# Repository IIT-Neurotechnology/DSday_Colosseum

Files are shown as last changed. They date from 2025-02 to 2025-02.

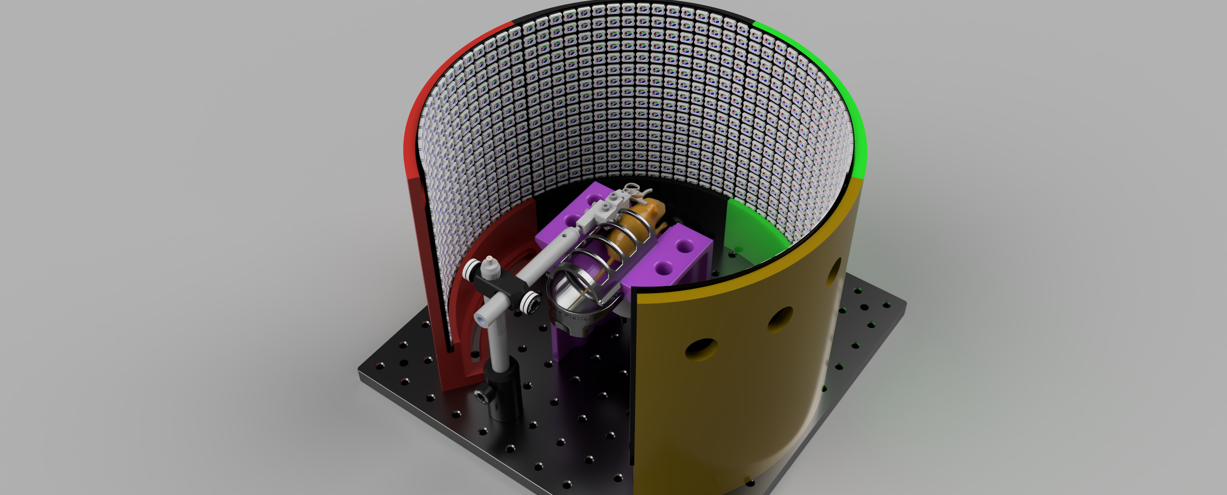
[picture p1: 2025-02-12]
NT_BMP005_004/NT_BMP005_004.png

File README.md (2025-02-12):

# BPOD-based Circular LED COLOSSEUM with Rotary Encoder Control

Render            |  Real
:-------------------------:|:-------------------------:
ed130eb8-e9cf-46bc-b179-3c29f74139bb | 663ee327-6ebf-47c2-a723-3dfb6b113a29

This system integrates a **BPOD** behavioral platform with a **circular LED display** and a **high-resolution rotary encoder**, creating a three-dimensional "colosseum-like" environment for a mouse in a neuroscience experiment. The mouse sits at the center of a 3D-printed, circular arena, surrounded by flexible LED panels. By turning a rotary encoder, the mouse effectively rotates a luminous vertical bar around the "walls" of this arena. Over time, the mouse can learn to anticipate the position of this bar, providing insights into spatial navigation and cognitive mapping.

---

## Hardware Components

- **BPOD Module**  
  Controls experimental states, rewards, and logs events. It synchronizes with the Teensy-based rotary encoder module and the LED display.

- **Rotary Encoder (1024 PPR)**  
  Translates the mouse's rotational input into LED position updates. The ratio `N` defines how many full rotations of the encoder correspond to a complete LED revolution. For example, `N = 2` means two wheel rotations produce one full LED ring rotation.

- **Flexible Circular LED Panels (WS2812B)**  
  - Four 16×16 LED matrices (each containing WS2812B LEDs) arranged in a 2×2 layout, forming a 64×16 (1024 LED) array.  
  - These are curved into a circular shape inside a 3D-printed enclosure.  
  - Each WS2812B LED needs ~1.25 µs per bit, **24 bits** (3 bytes for RGB), plus a ~50 µs reset at the end of the data stream.

- **BPOD Rotary Encoder Module (Teensy-based)**  
  A **Teensy** microcontroller reads the rotary encoder, calculates LED positions, and **sends** data over serial if required. A second Teensy can then handle the actual LED updates, preventing timing conflicts.

---

## Additional Teensy 3.6 for LED Control

To handle the large number of LEDs (1024 WS2812Bs) efficiently, a **second Teensy 3.6** is used **exclusively** for LED updates:

- **Faster LED Updates with FastLED**  
  - The second Teensy runs the **FastLED** library, which manages precise timing for WS2812B signals (~1.25 µs/bit).  
  - This Teensy listens on **Serial5** for packets containing LED bar indices and color commands.  
  - By splitting tasks across two microcontrollers, the rotary encoder readings remain accurate, and LED updates remain flicker-free.

- **Offloading CPU Load**  
  - The first Teensy (rotary encoder module) only sends position data to the second Teensy.  
  - This separation ensures smoother operation, as the CPU-intensive LED data updates occur on a dedicated microcontroller.

- **Two Data Pins for Higher Throughput**  
  - The second Teensy 3.6 drives the LEDs on **pins 18 and 19**, effectively splitting the 1024 LEDs into two parallel strips.  
  - Each LED requires 24 bits of data plus a ~50 µs reset at the end of the data frame. Driving two strips simultaneously nearly halves the total transmission time.

### Approximate Update Frequency Calculation

- **Single-Strip Transmission Time**  
  - Each LED needs 24 bits × 1.25 µs = 30 µs of transmission time per LED.  
  - For 1024 LEDs, total data time = 1024 × 30 µs = 30,720 µs, plus ~50 µs reset ≈ **30.77 ms** per frame.  
  - That’s about **32.5 fps** (frames per second) if you only had a single strip.

- **Two Strips in Parallel**  
  - If you split the 1024 LEDs into two equal strips, each strip updates 512 LEDs in parallel.  
  - Transmission time per strip is roughly 512 × 30 µs = 15,360 µs, plus ~50 µs ≈ **15.41 ms**.  
  - This yields around **65 fps** as a theoretical maximum, assuming continuous updates.

---
397879740-6fc6f9c6-3a99-4fa2-a4de-f5ea3d144b3a

## Software Components

- **BPOD State Machine**  
  Defines trial structures, handles reward timing, and synchronizes LED updates with behavioral events. The LED state can be triggered at certain times or after specific encoder changes, all logged by BPOD.

- **Teensy Firmware (C++ with FastLED)**  
  - **First Teensy** (Encoder Module)  
    Reads the rotary encoder and sends serial messages (via **Serial5**) containing updated LED positions or commands.  
  - **Second Teensy** (Dedicated LED Driver)  
    Receives data on **Serial5**, updates the WS2812B strips on pins 18 and 19, and ensures precise timing.

---

## Functionality

1. **Encoder-to-LED Mapping**  
   The encoder’s angular range maps onto the LED indices forming a circular ring. Each bar corresponds to a specific angular segment. Changing `N` modifies how many full turns of the encoder produce one full 360° LED sweep.

2. **Cylindrical Illusion**  
   The curved LED panels create a wraparound environment, giving the mouse the impression of a cylindrical “colosseum.” Rotating the encoder moves the illuminated bar around the circumference.

3. **Cognitive Task**  
   Mice can learn to anticipate the bar’s position, forming an internal “cognitive map” of the environment. Researchers can adjust difficulty by changing `N`, the **bar width** (`W`), or brightness.

4. **Minimal Updates**  
   Instead of resetting all 1024 LEDs every loop, the firmware switches off only the old bar and lights the new one. This approach minimizes computation, reduces flicker, and helps maintain brightness consistency.

---

## Setup & Calibration

1. **Hardware Assembly**  
   - 3D print the circular enclosure (e.g., on a Prusa) to hold four flexible 16×16 LED panels.  
   - Mount the LED panels around the inner circumference to form a 64×16 (1024 LED) array.  
   - Attach the rotary encoder, ensuring stable mechanical coupling for the mouse’s rotation.  
   - Use one Teensy for the rotary encoder and another Teensy 3.6 (with FastLED) for LED data.  
   - Provide sufficient power and stable wiring (WS2812B can draw significant current).

2. **Firmware & Parameters**  
   - Load the Teensy firmware for the encoder module (handles reading and serial output).  
   - Load the Teensy firmware for the LED driver (handles incoming serial commands and drives LEDs).  
   - Confirm `NUM_LEDS = 1024` (or your actual total), and that two strips of 512 LEDs are mapped to pins 18 & 19.  
   - Set `N` for the desired encoder rotations per 360° sweep. Adjust `W` (the bar width in LEDs) and LED brightness to tune performance and difficulty.

3. **BPOD Integration**  
   - Configure BPOD’s state machine to detect encoder triggers and LED transitions.  
   - Optionally deliver rewards when certain encoder conditions are met.  
   - Use BPOD’s data logging to correlate behavior, encoder events, and LED states.

---

## Maintenance & Troubleshooting

- **LED/Encoder Alignment**  
  If LED positions don’t match the encoder reading, verify the index mapping and `N` factor.  
- **Power Supply**  
  Flickering or dim LEDs may indicate insufficient power or significant voltage drop. Use robust wiring and/or inject power at multiple points.  
- **Frame Rate Optimization**  
  If you need faster updates, switch to 4 pins to achieve a faster parallel communication with the LEDs
- **Serial Communication**  
  Ensure the second Teensy is receiving data correctly on **Serial5** (check baud rate, TX/RX pins).

---

## Conclusion

This integrated system provides a precise, stable, and configurable visual environment for neuroscience experiments. By combining a **BPOD** state machine, a **high-resolution rotary encoder**, and **two Teensy 3.6** boards (one exclusively handling **FastLED** updates), researchers can study spatial cognition in rodents. Efficient partial‐update LED control ensures smooth visuals, aiding in the formation of robust internal cognitive maps in the mouse’s brain.

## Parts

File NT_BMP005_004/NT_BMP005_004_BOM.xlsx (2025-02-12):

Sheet: components request
# | Cod. | Rev. | Q.ty | Mfg. Technology | Material | Notes | Optional column 1 | Optional column 2
1 | NT_BMP005_004 | 1 | 1 | FFF (Fortus400) | any

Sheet: processes
Mgf. Technologies
Additive Mfg. (any)
SLS (ProX6100)
Polyjet (Connex500)
SLA (XFAB3500SD)
FFF (Fortus400)
CNC / Machine Tools
Waterjet
Inserts/Helicoils
Mech. Assembly
Reworked Comp.
Other

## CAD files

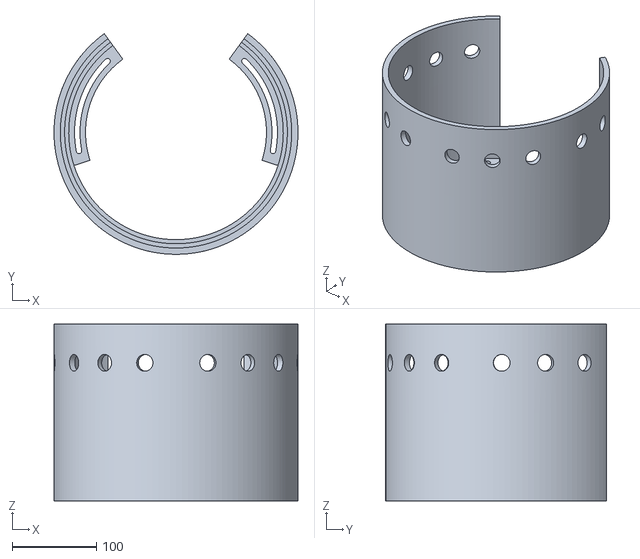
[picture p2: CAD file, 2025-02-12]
NT_BMP005_004/NT_BMP005_004.stl
290.0 x 262.3 x 210.0

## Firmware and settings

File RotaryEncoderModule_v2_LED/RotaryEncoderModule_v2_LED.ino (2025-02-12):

/*
  ----------------------------------------------------------------------------

  This file is part of the Sanworks Bpod_Gen2 repository
  Copyright (C) 2022 Sanworks LLC, Rochester, New York, USA

  ----------------------------------------------------------------------------

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
*/

// The rotary encoder module, powered by Teensy 3.5 (v1) or 4.0 (v2), interfaces the Bpod state machine with a quadrature rotary encoder (e.g. Yumo E6B2-CWZ3E)
// The serial interface allows the state machine to set position thresholds which generate Bpod events when crossed, and to reset the encoder position.
// The MATLAB interface can capture streaming position data and set new thresholds.

#define FirmwareVersion 6
#define HARDWARE_VERSION 1 // NOTE: SET THIS TO MATCH THE TARGET VERSION OF THE MODULE! You MUST uncomment the next line if compiling for HARDWARE_VERSION 2
// #include "QuadEncoder.h"

#include "ArCOM.h"
#include <SPI.h>
#include "SdFat.h"
#include "FastLED.h"

#if HARDWARE_VERSION == 1
  SdFs SDcard;
  FsFile DataFile; // File on microSD card, to store waveform data
  bool ready = false; // Indicates if SD is busy (for use with SDBusy() funciton)
#else
  QuadEncoder hwEnc(1, 7, 8);
  IntervalTimer hardwareTimer;
#endif
ArCOM myUSB(SerialUSB); // USB is an ArCOM object. ArCOM wraps Arduino's SerialUSB interface

#if HARDWARE_VERSION == 1
  ArCOM StateMachineCOM(Serial3); // UART serial port
  ArCOM OutputStreamCOM(Serial2); // UART serial port
#elif HARDWARE_VERSION == 2
  ArCOM StateMachineCOM(Serial1);
#endif
// Module setup
char moduleName[] = "RotaryEncoder"; // Name of module for manual override UI and state machine assembler

// Output stream setup
char moduleStreamPrefix = 'M'; // Command character to send before each position value when streaming data via output stream jack
byte outputStreamDatatype = 'H'; // Integer type to use when streaming position value. 'H' = 16-bit unsigned int, 'L' = 32-bit unsigned int

// Hardware setup
#if HARDWARE_VERSION == 1
  const byte EncoderPinA = 35;
  const byte EncoderPinB = 36;
  const byte EncoderPinZ = 37;
  byte circuitRevisionArray[5] = {26,27,28,29,30};
#elif HARDWARE_VERSION == 2
  const byte EncoderPinA = 8;
  const byte EncoderPinB = 7;
  const byte EncoderPinZ = 6;
  byte circuitRevisionArray[5] = {17,18,19,20,21};
#endif

#if HARDWARE_VERSION == 2
  const byte DAC_CS_Pin = 10;
  SPISettings DACSettings(30000000, MSBFIRST, SPI_MODE0); // Settings for DAC
  byte dacBuffer[3] = {0}; // Holds bytes to be written to the DAC
  union {
    byte byteArray[4];
    uint16_t uint16[2];
  } dacValue;
#endif

// Constants
const uint16_t logic3v3_bits = 52748; // Bits for 3.3V on 16-bit DAC register spanning 0-4.1V

// Parameters
const byte maxThresholds = 8;
int16_t thresholds[maxThresholds] = {0}; // Initialized by client. Position range = -512 : 512 encoder tics, corresponding to -180 : +180 degrees
boolean thresholdActive[maxThresholds] = {true}; // Thresholds are inactivated on crossing, until manually reset
byte thresholdTypes[maxThresholds] = {0}; // Type 0 (Threshold reached when position crossed) Type 1 (After enable, threshold reached after Time spent within +/- position)
uint32_t thresholdTimes[maxThresholds] = {0}; // For thresholdType 1, time parameter. Units = # of 100μs hardware timer cycles.
int16_t nextTrialThresholds[maxThresholds] = {0}; // Thresholds for next trial (thresholds is set to this on next call to the '*' (push) command)
byte nextTrialThresholdTypes[maxThresholds] = {0}; // Threshold types for next trial (thresholdTypes is set to this on next call to the '*' (push) command)
uint32_t nextTrialThresholdTimes[maxThresholds] = {0}; // Threshold times for next trial (thresholdTimes is set to this on next call to the '*' (push) command)
byte nThresholds = maxThresholds; // Number of thresholds currently used
byte nextTrialnThresholds = 0; // Number of thresholds for next trial (nThresholds is set to this on next call to the '*' (push) command)
int decouplingflag=1;
int counter=0;
#if HARDWARE_VERSION == 1
  int16_t wrapPoint = 2048; // Position used to wrap position. At 512, if position > 512 or < -512, position wraps to -512 and 512 respectively.
#else
  int16_t wrapPoint = 2048;
#endif
int nWraps = 0; // number of times (positive or negative) that the wheel position has wrapped since last reset

// State variables
boolean usbStreaming = false; // If currently streaming position and time data to the output-stream port
boolean sendEvents = true; // True if sending threshold crossing events to state machine
boolean isLogging = false; // If currently logging position and time to microSD memory
boolean moduleStreaming = false; // If streaming position to a separate module via the output stream jack (preconfigured output for DDS module)
boolean newThresholdsLoaded = false; // If new 'advanced' thresholds were loaded to the device with 't' command (different from legacy 'T')
int16_t EncoderPos = 0; // Current position of the rotary encoder
int16_t LastEncoderPos = 0; // Last known position of rotary encoder
byte currentDir = 0; // Current direction (0 = clockwise, 1 = counterclockwise)
byte outputSyncLogic[2] = {0};

// Program variables
byte testByte = 0;
byte opCode = 0;
byte opSource = 0;
byte param = 0;
boolean newOp = false;
boolean loggedDataAvailable = 0;
boolean wrappingEnabled = true;
byte wrapMode = 0;
boolean EncoderPinAValue = 0;
boolean LastEncoderPinAValue = 0;
boolean EncoderPinBValue = 0;
uint32_t dataPos = 0;
uint32_t dataMax = 4294967295; // Maximim number of positions that can be logged (limited by 32-bit counter)
elapsedMicros currentTime;
int16_t wrapPointInverse = 0;
uint32_t thresholdTimeElapsed[maxThresholds] = {0}; // Current time (number of timer cycles) since threshold was enabled
int16_t ThresholdPos[maxThresholds] = {0}; // A separate position value for time thresholds (time spent within position range; threshold type 1)
int16_t EncoderPosChange = 0; // Change in position, used to reset timer when using time thresholds
union {
    byte uint8[4];
    uint16_t uint16;
    uint32_t uint32;
} typeBuffer;

#if HARDWARE_VERSION == 1
  // microSD variables
  uint32_t nRemainderBytes = 0;
  uint32_t nFullBufferReads = 0;
  union {
      byte uint8[800];
      uint32_t int32[200];
  } sdWriteBuffer;
  const uint32_t sdReadBufferSize = 2048; // in bytes
  uint8_t sdReadBuffer[sdReadBufferSize] = {0};
#endif

// Interrupt and position buffers
const uint32_t positionBufferSize = 1024;
int16_t positionBuffer[positionBufferSize][2] = {0};
int32_t timeBuffer[positionBufferSize][2] = {0};
uint32_t iPositionBuffer[2] = {0};
uint32_t thisInd = 0;
boolean positionBufferFlag = false;
byte currentPositionBuffer = 0;
byte thisPositionBuffer = 0;
uint32_t currentInd = 0;

// Event buffer
byte newEventType = 0; // 0 = State Machine, (Not yet implemented: 1 = TTL Ch 18, 2 = TTL Ch 19, 3 = I2C)
byte newEventCode = 0; // The new event (if state machine or I2C, a byte; if TTL, a logic level)
uint32_t newEventTime = 0;
boolean newEvent = 0;

// USB streaming buffer
const uint32_t usbStreamingBufferSize = 1000;
uint32_t usbStreamingBufferPos = 0;
byte usbStreamingBuffer[usbStreamingBufferSize] = {0};
uint32_t nPositions = 0;
byte circuitRevision = 0; // Minor revision of circuit board
uint16_t TestVal = 0;

void setup() {
  // put your setup code here, to run once:
  setupLED();
  SerialUSB.begin(115200);
  #if HARDWARE_VERSION == 1
    Serial3.begin(1312500);
    Serial2.begin(1312500);
  #elif HARDWARE_VERSION == 2
    Serial1.begin(1312500);
  #endif
  SPI.begin();
  #if HARDWARE_VERSION == 1
    pinMode(EncoderPinA, INPUT);
    pinMode (EncoderPinB, INPUT);
    SDcard.begin(SdioConfig(FIFO_SDIO));
    SDcard.remove("Data.wfm");
    DataFile = SDcard.open("Data.wfm", O_RDWR | O_CREAT);
    DataFile.preAllocate(1000000);
    while (sdBusy()) {}
    DataFile.seek(0);
  #endif
  #if HARDWARE_VERSION == 2
    hwEnc.setInitConfig();
    hwEnc.init();
    pinMode(DAC_CS_Pin, OUTPUT);
    digitalWrite(DAC_CS_Pin, HIGH);
    SPI.beginTransaction(DACSettings);
    powerUpDAC();
  #endif
  wrapPointInverse = wrapPoint * -1;
  // Read hardware revision from circuit board (an array of grounded pins indicates revision in binary, grounded = 1, floating = 0)
  circuitRevision = 0;
  for (int i = 0; i < 5; i++) {
    pinMode(circuitRevisionArray[i], INPUT_PULLUP);
    circuitRevision += pow(2, i)*digitalRead(circuitRevisionArray[i]);
    pinMode(circuitRevisionArray[i], INPUT);
  }
  circuitRevision = 31-circuitRevision;
  #if HARDWARE_VERSION == 1
    attachInterrupt(EncoderPinA, updatePosition, CHANGE);
  #else
    hardwareTimer.begin(updatePosition, 100);
  #endif
}

void loop() {
  loopLED();
  if (myUSB.available() > 0) {
    opCode = myUSB.readByte();
    newOp = true;
    opSource = 0;
  } else if (StateMachineCOM.available() > 0) {
    opCode = StateMachineCOM.readByte();
    newOp = true;
    opSource= 1;
  #if HARDWARE_VERSION == 1
  } else if (OutputStreamCOM.available() > 0) {
    opCode = OutputStreamCOM.readByte();
    newOp = true;
    opSource = 2;
  #endif
  }
  if (newOp) {
    newOp = false;
    switch(opCode) {
      case 255: // Return module name and info
        if (opSource == 1) { // If requested by state machine
          returnModuleInfo();
        }
      break;
      #if HARDWARE_VERSION == 1 
        case 254: // Relay test byte from USB to echo module, or from echo module back to USB 
          if (opSource == 0) {
            OutputStreamCOM.writeByte(254);
          }
          if (opSource == 2) {
            myUSB.writeByte(254);
          }
        break;
      #endif
      case 'C': // USB Handshake
        if (opSource == 0) {
          myUSB.writeByte(217);
        }
      break;
      #if HARDWARE_VERSION == 1 
        case 200: // Byte forwarding (Diagnostic)
          switch (opSource) {
            case 0:
              testByte = myUSB.readByte();
              OutputStreamCOM.writeByte(testByte);
            break;
            case 1:
              testByte = myUSB.readByte();
              StateMachineCOM.writeByte(testByte);
            break;
          }
        break;
        case 201: // Byte forwarding (Diagnostic)
          switch (opSource) {
            case 2:
              myUSB.writeByte(201);
            break;
          }
        break;
      #endif
      case 'S': // Start/Stop USB position+time data stream
        if (opSource == 0) {
          usbStreaming = myUSB.readByte();
          if (usbStreaming) {
            EncoderPos = 0; // Reset position
            nWraps = 0; // Reset wrap counter
            currentTime = 0; // Reset clock
          }
        }
      break;
      case 'O': // Start/Stop module position data stream
        moduleStreaming = readByteFromSource(opSource);
        if (opSource == 0) {
          myUSB.writeByte(1); // Confirm
        }
      break;
      case 'V': // Set event transmission to state machine (on/off)
      if (opSource == 0) {
        sendEvents = myUSB.readByte();
        myUSB.writeByte(1);
      }
      break;
      case '#': // Log an incoming event and the current time
        if (opSource == 1) {
          newEventCode = StateMachineCOM.readByte();
          newEventTime = currentTime;
          newEventType = 0; // 0 = State Machine, (Not yet implemented: 1 = TTL Ch 18, 2 = TTL Ch 19, 3 = I2C)
          if (usbStreaming) {
            usbStreamingBuffer[0] = 'E';
            usbStreamingBuffer[1] = newEventType; // State machine event type (0 = 
            usbStreamingBuffer[2] = newEventCode; // State machine event code
            typeBuffer.uint32 = newEventTime; // State machine event time on RE module clock
            usbStreamingBuffer[3] = typeBuffer.uint8[0];
            usbStreamingBuffer[4] = typeBuffer.uint8[1];
            usbStreamingBuffer[5] = typeBuffer.uint8[2];
            usbStreamingBuffer[6] = typeBuffer.uint8[3];
            myUSB.writeByteArray(usbStreamingBuffer, 7);
          }
          newEvent = true;
        }
      break;
      case 'W': // Set wrap point (in tics)
      if (opSource == 0) {
        wrapPoint = myUSB.readInt16();
        myUSB.writeByte(1);
        if (wrapPoint != 0) {
          wrappingEnabled = true;
        } else {
          wrappingEnabled = false;
        }
        wrapPointInverse = wrapPoint * -1;
        nWraps = 0;
        if ((EncoderPos > wrapPoint) || (EncoderPos < wrapPointInverse)) {
          EncoderPos = wrapPoint;
        }
      }
      break;
      case 'M': // Set wrap Mode: 0 bipolar (wrap to negative wrapPoint), 1 = unipolar (wrap to zero)
        if (opSource == 0) {
          wrapMode = myUSB.readByte(); // Read number of thresholds to program
          myUSB.writeByte(1);
        }
      break;
      case 'T': // Program simple position thresholds (effective immediately)
        if (opSource == 0) {
          param = myUSB.readByte(); // Read number of thresholds to program
          if (param <= maxThresholds) {
            nThresholds = param;
            for (int i = 0; i < nThresholds; i++) {
              thresholds[i] = myUSB.readInt16();
              thresholdTypes[i] = 0;
              thresholdTimes[i] = 0;
            }
            myUSB.writeByte(1);
          } else {
            myUSB.writeByte(0);
          }
        }
      break;
      case 't': // Program 'advanced' thresholds to hold in storage buffer until next call to '*' (the 'push' command). HW version 2 only!
                // No confirmation byte is returned, for compatability with whole-session USB position streaming
                // Advanced thresholds can be: Type 0 (Threshold reached when position crossed) Type 1 (After enable, threshold reached after Time spent within +/- position)
        #if HARDWARE_VERSION > 1 
          if (opSource == 0) {
            param = myUSB.readByte();
            if (param <= maxThresholds) { // Read number of thresholds to program
              nextTrialnThresholds = param;
              myUSB.readByteArray(nextTrialThresholdTypes, nextTrialnThresholds);
              myUSB.readInt16Array(nextTrialThresholds, nextTrialnThresholds);
              myUSB.readUint32Array(nextTrialThresholdTimes, nextTrialnThresholds); // Units = HW timer cycles (# of 100μs intervals)
              newThresholdsLoaded = true;
            }
          }
        #endif
      break;
      case '*': // The 'Push' command sets any advanced thresholds previously loaded with the 't' command to be the current thresholds
        if (newThresholdsLoaded) {
          for (int i = 0; i < nextTrialnThresholds; i++) {
            thresholds[i] = nextTrialThresholds[i];
            thresholdTypes[i] = nextTrialThresholdTypes[i];
            thresholdTimes[i] = nextTrialThresholdTimes[i];
          }
          nThresholds = nextTrialnThresholds;
          newThresholdsLoaded = false;
        }
      break;
      case 'I': // Set 1-character prefix preceding each position data point streamed to a receiving Bpod module
        if (opSource == 0) {
          #if HARDWARE_VERSION == 1
            moduleStreamPrefix = myUSB.readByte();
            myUSB.writeByte(1);
          #else
            myUSB.writeByte(0);
          #endif
        }
      break;
      case ';': // Set enable/disable status of all thresholds
        param = readByteFromSource(opSource);
        for (int i = 0; i < nThresholds; i++) {
          thresholdActive[i] = bitRead(param, i);
          if (thresholdActive[i]) {
            thresholdTimeElapsed[i] = 0;
            ThresholdPos[i] = 0;
          }
        }
        nWraps = 0;
      break;
      case 'Z': // Zero position
        EncoderPos = 0;
        #if HARDWARE_VERSION == 2
          hwEnc.write(0);
        #endif
        nWraps = 0;
        if (usbStreaming) {
          newEventTime = currentTime;
          usbStreamingBuffer[0] = 'P'; // Code for position data
          usbStreamingBuffer[1] = 0;
          usbStreamingBuffer[2] = 0;
          typeBuffer.uint32 = newEventTime; // Time
          usbStreamingBuffer[3] = typeBuffer.uint8[0]; 
          usbStreamingBuffer[4] = typeBuffer.uint8[1];
          usbStreamingBuffer[5] = typeBuffer.uint8[2];
          usbStreamingBuffer[6] = typeBuffer.uint8[3];
          myUSB.writeByteArray(usbStreamingBuffer, 7);
        }
      break;
      case 'E': // Enable all thresholds
        for (int i = 0; i < nThresholds; i++) {
          thresholdActive[i] = true;
          ThresholdPos[i] = 0;
          thresholdTimeElapsed[i] = 0;
        }
        nWraps = 0;
      break;
      case 'L': // Start microSD logging
        #if HARDWARE_VERSION == 1
          startLogging();
        #endif
      break;
      case 'F': // finish microSD logging
        #if HARDWARE_VERSION == 1
          logCurrentPosition();
          isLogging = false;
          if (dataPos > 0) {
            loggedDataAvailable = true;
          }
        #endif
      break;
      case 'R': // Return logged data
        if (opSource == 0) {
          #if HARDWARE_VERSION == 1
            isLogging = false;
            if (loggedDataAvailable) {
              loggedDataAvailable = false;
              DataFile.seek(0);
              if (dataPos*8 > sdReadBufferSize) {
                nFullBufferReads = (unsigned long)(floor(((double)dataPos)*8 / (double)sdReadBufferSize));
              } else {
                nFullBufferReads = 0;
              }
              myUSB.writeUint32(dataPos);     
              for (int i = 0; i < nFullBufferReads; i++) { // Full buffer transfers; skipped if nFullBufferReads = 0
                DataFile.read(sdReadBuffer, sdReadBufferSize);
                
                myUSB.writeByteArray(sdReadBuffer, sdReadBufferSize);
              }
              nRemainderBytes = (dataPos*8)-(nFullBufferReads*sdReadBufferSize);
              if (nRemainderBytes > 0) {
                DataFile.read(sdReadBuffer, nRemainderBytes);
                myUSB.writeByteArray(sdReadBuffer, nRemainderBytes);     
              }              
              dataPos = 0;
            } else {
              myUSB.writeUint32(0);
            }
          #endif
        }
      break;
      case 'Q': // Return current encoder position
        if (opSource == 0) {
          myUSB.writeInt16(EncoderPos);
        }
      break;
      case 'P': // Set current encoder position
        if (opSource == 0) {
          EncoderPos = readInt16FromSource(opSource);
          #if HARDWARE_VERSION == 2
            hwEnc.write((uint32_t)EncoderPos);
          #endif
          nWraps = 0;
          myUSB.writeByte(1);
        }
      break;
      case 'X': // Reset all data streams
        resetDataStreams();
      break;
      case 'U':
        decouplingflag = !decouplingflag;
        #if HARDWARE_VERSION == 2
          hwEnc.write((uint32_t)EncoderPos);
        #endif
          nWraps = 0;
        if (opSource == 0) {
          myUSB.writeByte(1);
          }
      break;
    } // End switch(opCode)
  } // End if (SerialUSB.available())
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

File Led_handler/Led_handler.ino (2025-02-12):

/*********************************************************
 * RECEIVER for a 5-byte packet:
 *   [0x55][decoupled][hiIndex][loIndex][0x11]
 *
 * If SCREENSAVER is defined, it will continuously
 * animate a "bouncing line" until the *first* valid
 * serial packet arrives, at which point normal operation
 * begins.
 *********************************************************/
#include <Arduino.h>
#include <FastLED.h>

/* ---------- SCREENSAVER Feature Flag ---------- */
// Comment this out if you *don't* want a screensaver
//#define SCREENSAVER

#ifdef SCREENSAVER
bool screensaverActive = true;  // start in screensaver mode
#endif

/* ---------- CONFIG & GEOMETRY ---------- */
#define NUM_PANELS 4
#define PANEL_WIDTH 16
#define PANEL_HEIGHT 16
#define W 2
#define NUM_BARS (NUM_PANELS * PANEL_WIDTH) // 64
#define NUM_LEDS (PANEL_WIDTH * PANEL_HEIGHT * NUM_PANELS)
#define BRIGHTNESS 200

#define DATA_PIN 18
#define DATA_PIN2 19

#define NUM_STRIPS 2
#define LEDS_PER_STRIP (NUM_LEDS / NUM_STRIPS)

/************* LED ARRAYS ****************/
CRGB ledsA[LEDS_PER_STRIP];
CRGB ledsB[LEDS_PER_STRIP];

/************* PACKET DEFINES ************/
static const uint8_t START_BYTE = 0x55;
static const uint8_t END_BYTE   = 0x11;

/************* PACKET STATE **************/
bool    decoupled    = true;
int16_t currentIndex = 0;  // note it's signed

/************* INTERNAL STATE ************/
int  prevIndex = 10000; 
int  cdecoup   = 0;

/**********************************************************************
 * setLED: Utility to set a single LED by global index
 **********************************************************************/
void setLED(int idx, const CRGB &color) {
  if (idx < 0 || idx >= NUM_LEDS) return;
  if (idx < LEDS_PER_STRIP) {
    ledsA[idx] = color;
  } else {
    ledsB[idx - LEDS_PER_STRIP] = color;
  }
}

/**********************************************************************
 * LEDLine Class
 **********************************************************************/
class LEDLine {
public:
  LEDLine(int startIndex, CRGB color = CRGB::White)
    : m_start(startIndex), m_color(color)
  {
    m_length = PANEL_HEIGHT * W; 
  }

  void setStart(int startIndex) {
    m_start = startIndex;
  }

  void setColor(const CRGB& color) {
    m_color = color;
  }

  void draw() {
    for (int i = 0; i < m_length; i++) {
      int ledIndex = (m_start * PANEL_HEIGHT) + i;
      // wrap safely
      ledIndex = (ledIndex + NUM_LEDS) % NUM_LEDS;
      setLED(ledIndex, m_color);
    }
  }

  void clear() {
    for (int i = 0; i < m_length; i++) {
      int ledIndex = (m_start * PANEL_HEIGHT) + i;
      ledIndex = (ledIndex + NUM_LEDS) % NUM_LEDS;
      setLED(ledIndex, CRGB::Black);
    }
  }

  void clearAll() {
    // Clears entire array
    for (int i = 0; i < LEDS_PER_STRIP; i++) {
      ledsA[i] = CRGB::Black;
      ledsB[i] = CRGB::Black;
    }
  }

private:
  int  m_start;   
  int  m_length;  
  CRGB m_color;
};

CRGB lineColor = CRGB::Green;
LEDLine line(0, lineColor);
LEDLine oldline(prevIndex, CRGB::Black);

/**********************************************************************
 * screensaverAnimationStep():
 *  A single "step" of a bouncing line, so that we can
 *  check for new serial data on each iteration.
 **********************************************************************/
#ifdef SCREENSAVER
void screensaverAnimationStep() {
  static int bar       = 0;
  static int direction = 1;  // +1 forward, -1 backward

  // Clear everything
  FastLED.clear();

  // Draw a line at "bar"
  line.setStart(bar);
  line.draw();

  FastLED.show();

  // Move "bar" for next time
  bar += direction;
  // Bounce if we reach the extremes
  if (bar >= NUM_BARS) {
    bar = NUM_BARS - 1;
    direction = -1;
  } else if (bar < 0) {
    bar = 0;
    direction = 1;
  }
}
#endif

/**********************************************************************
 * setup()
 **********************************************************************/
void setup() {
  Serial.begin(115200);
  Serial.println("Receiver: Setup start");

  // Listen on Serial5
  Serial5.begin(115200);

  // FastLED setup
  FastLED.addLeds<NEOPIXEL, DATA_PIN >(ledsA, LEDS_PER_STRIP);
  FastLED.addLeds<NEOPIXEL, DATA_PIN2>(ledsB, LEDS_PER_STRIP);
  FastLED.setBrightness(BRIGHTNESS);

  FastLED.clear();
  FastLED.show();

#ifdef SCREENSAVER
  Serial.println("Screensaver Mode: will continue until first valid packet...");
#else
  Serial.println("No Screensaver Mode: normal operation");
#endif

  Serial.println("Receiver: Setup complete");
}

/**********************************************************************
 * loop()
 **********************************************************************/
void loop() {

#ifdef SCREENSAVER
  // If we're still in screensaver mode, check if a packet arrives
  if (screensaverActive) {
    // Attempt to read the first valid packet
    while (Serial5.available() >= 5) {
      if (Serial5.peek() == START_BYTE) {
        // If we read a valid packet, disable screensaver
        if (readPacket()) {
          screensaverActive = false;
          Serial.println("Screensaver disabled: Received first valid packet!");
          // Act on that packet
          FastLED.clear();
          updateLEDs();
          return; // done for this loop
        } else {
          // readPacket() failed, discard 1 byte to resync
          Serial5.read();
        }
      } else {
        // Not START_BYTE, discard 1 byte
        Serial5.read();
      }
    }

    // If we get here, no valid packet arrived this loop iteration
    // => keep running the screensaver
    screensaverAnimationStep();
    return; // end loop() here so we don't do normal logic below
  }
#endif

  // ----- Normal, Non-Screensaver Operation -----

  bool gotNewPacket = false;  // track if we got at least one valid packet

  // Keep trying to read as long as there's enough data for a 5-byte packet
  while (Serial5.available() >= 5) {
    // If the next byte is our START_BYTE, attempt to read the packet
    if (Serial5.peek() == START_BYTE) {
      if (readPacket()) {
        // We successfully read a 5-byte packet
        gotNewPacket = true;
      } else {
        // If readPacket() failed, discard one byte to resync
        Serial5.read();
      }
    } else {
      // If it's not START_BYTE, discard one byte
      Serial5.read();
    }
  }

  // Only update LEDs after we've read *all* pending packets
  if (gotNewPacket) {
    updateLEDs();
  }
}
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

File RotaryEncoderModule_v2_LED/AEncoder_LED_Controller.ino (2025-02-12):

/************************************************************
 * Minimal SENDER TEENSY CODE
 * 
 * Responsibilities:
 *   1) Calculates the bar index from EncoderPos.
 *   2) Sends it (plus decoupling flag) via Serial5.
 *   3) No LED logic, no virtual logic, minimal updates.
 * 
 * Wiring (Serial5):
 *   - Sender (REM) TX5 (pin 33) -> Receiver (EXT_Teensy) RX5 (pin 31) 
 *   - Sender (REM) RX5 (pin 34) -> Receiver (EXT_Teensy) TX5 (pin 32)
 *   - Shared GND
 ************************************************************/

/* ---------- PROTOCOL (Packet) DEFINITION ---------- */
static const uint8_t START_BYTE = 0x55;
static const uint8_t END_BYTE   = 0x11;

/* ---------- GEOMETRY CONSTANTS ---------- */
#define PPR               1024
#define NUM_PANELS        4
#define NUM_VIRTUAL_PANELS 1
#define PANEL_WIDTH       16
#define PANEL_HEIGHT      16
#define NUM_BARS          (NUM_PANELS * PANEL_WIDTH) // 64
#define NUM_VIRTUAL_BARS  (NUM_VIRTUAL_PANELS * PANEL_WIDTH)
#define W                 1

//#define DEBUG

/* ----------
   EXTERNAL variables (assumed updated elsewhere):
      EncoderPos       (range ~ -wrapPoint..+wrapPoint)
      wrapPoint        (e.g., 2048)
      wrapPointInverse (e.g., -2048)
      decouplingflag   (0 or 1)
---------- */
extern int16_t EncoderPos;
extern int16_t wrapPoint;
extern int16_t wrapPointInverse;
extern int     decouplingflag;

/* ---------- PROTOTYPES ---------- */
static void sendIndexOverSerial5(int16_t ledIndex, bool decoupled);

/* 
   Track the last index we sent so we only update
   the receiver when something changes.
*/
static int16_t lastIndex = 9999; // an impossible sentinel

/* -----------------------------------------------------
   setupLED: Initialize Serial5 (no LED logic here)
------------------------------------------------------*/
void setupLED() {
  #ifdef DEBUG
    Serial.begin(115200);
    Serial.println("Sender: setupLED()");
  #endif

  // Initialize Serial5 for communication
  Serial5.begin(115200);

  // Initialize lastIndex if desired
  lastIndex = 9999;
}

/* -----------------------------------------------------
   loopLED: 
   1) Checks decoupling.
   2) Maps EncoderPos => ledIndex in normal mode.
   3) Sends only if there's a change.
------------------------------------------------------*/
void loopLED() {
  // If decoupled, send a special index = -1, but only once
  if (decouplingflag == 1) {
    if (lastIndex != -1) {
      // We just switched to decoupled
      #ifdef DEBUG
        Serial.println("Sender: decoupled -> sending -1");
      #endif
      sendIndexOverSerial5(-1, true);
      lastIndex = -1;  // So we won't resend until decouplingflag goes 0 again
    }
    // No further normal index calculations in decoupled mode
    return;
  }

  // Normal operation: map the EncoderPos to a LED bar index
  int16_t ledIndex = map(
    EncoderPos,
    -wrapPointInverse,  // typically +2048
    -wrapPoint,         // typically -2048
     0, 
    (NUM_BARS + NUM_VIRTUAL_BARS - 1)
  );

  // Optional offset if you want to center the line visually
  ledIndex -= (PANEL_WIDTH + W) / 2;

  // If the new index is different, send it
  if (ledIndex != lastIndex) {
    #ifdef DEBUG
      Serial.print("Sender: ledIndex changed -> ");
      Serial.println(ledIndex);
    #endif
    sendIndexOverSerial5(ledIndex, false);
    lastIndex = ledIndex;
  }
}

/* -----------------------------------------------------
   sendIndexOverSerial5: 
   Sends 1 start byte, 1 decoupled byte, 2 index bytes,
   1 end byte.
------------------------------------------------------*/
static void sendIndexOverSerial5(int16_t ledIndex, bool decoupled) {
  Serial5.write(START_BYTE);              // 0x55
  Serial5.write(decoupled ? 1 : 0);       // decoupled flag (1 or 0)

  // ledIndex as 16-bit signed
  uint8_t highByte = (uint8_t)((ledIndex >> 8) & 0xFF);
  uint8_t lowByte  = (uint8_t)(ledIndex & 0xFF);

  Serial5.write(highByte);
  Serial5.write(lowByte);
  Serial5.write(END_BYTE);                // 0x11

  #ifdef DEBUG
    Serial.print("Sender: Packet sent -> decoupled=");
    Serial.print(decoupled ? 1 : 0);
    Serial.print(", index=");
    Serial.println(ledIndex);
  #endif
}

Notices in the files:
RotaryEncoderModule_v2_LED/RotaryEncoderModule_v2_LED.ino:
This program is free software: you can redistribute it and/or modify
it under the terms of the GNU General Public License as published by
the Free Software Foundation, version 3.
